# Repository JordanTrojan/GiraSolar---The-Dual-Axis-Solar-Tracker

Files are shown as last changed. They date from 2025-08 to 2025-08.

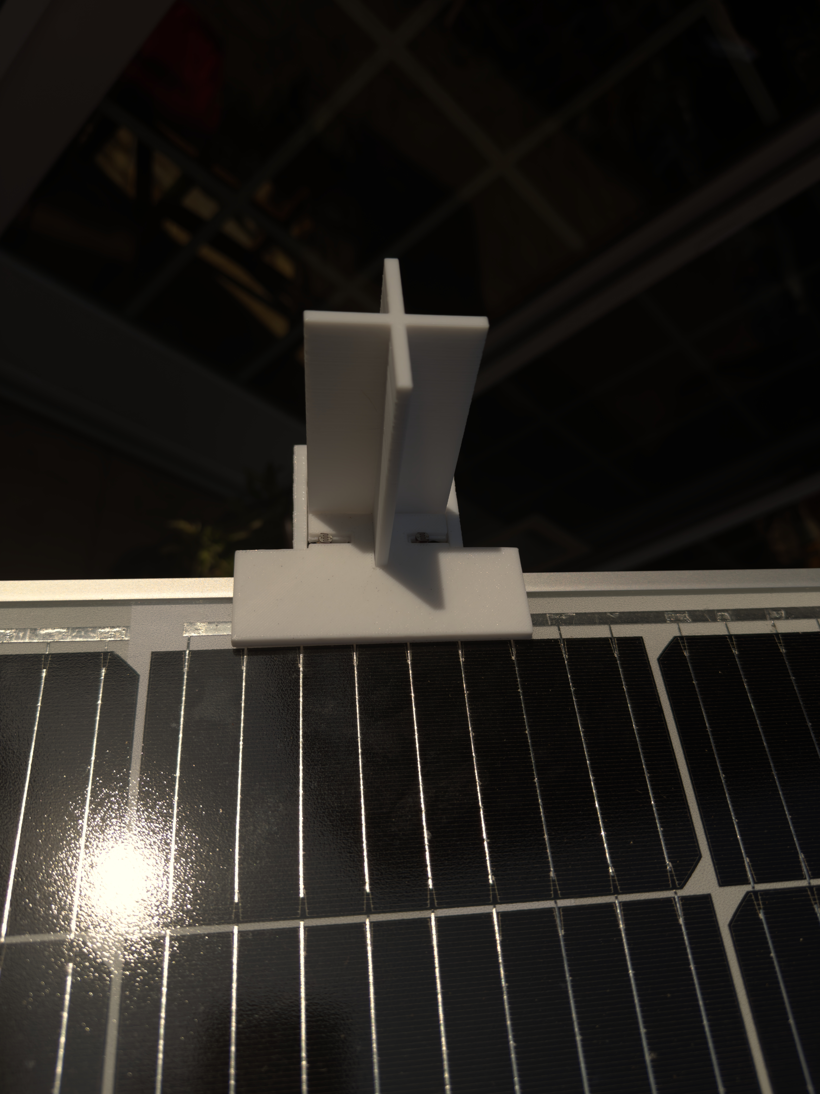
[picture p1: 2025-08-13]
Images and Timelapse/IMG_7817.jpg

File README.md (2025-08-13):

# GiraSolar---The-Dual-Axis-Solar-Tracker
The affordable dual axis solar system that hold up to three solar panels and inceases efficiency by 43% throughout the day. 
The GiraSolar Dual-Axis Tracking Project is an advanced solar tracking system designed to maximize photovoltaic efficiency by keeping the solar panel at the optimal orientation relative to the sun’s position throughout the day and across the seasons. The system operates with a north–south tilt range of 30° to 105° and an east–west rotation range of 45° to 135°, ensuring maximum sunlight exposure from early morning to late afternoon while also maintaining optimal seasonal alignment.

An Arduino Uno microcontroller serves as the control hub, running a custom tracking algorithm. Sun position is determined using an array of photoresistor (LDR) light sensors arranged in a cross-pattern to detect directional light differences. Movement is provided by two high-torque linear actuators—one for NS tilt and one for EW rotation—each driven by a BTS7960 motor driver module for smooth and precise positioning.

The system is powered via a solar charge controller connected to the main panel and battery, ensuring reliable operation in off-grid conditions. To protect the mechanics, limit switches and programmed motion boundaries prevent overextension of the actuators. The frame is made from rigid, lightweight materials, designed for stability under outdoor conditions but not intended for rain or water exposure; as such, the electronics and actuators require a sheltered or dry environment for operation and longevity.

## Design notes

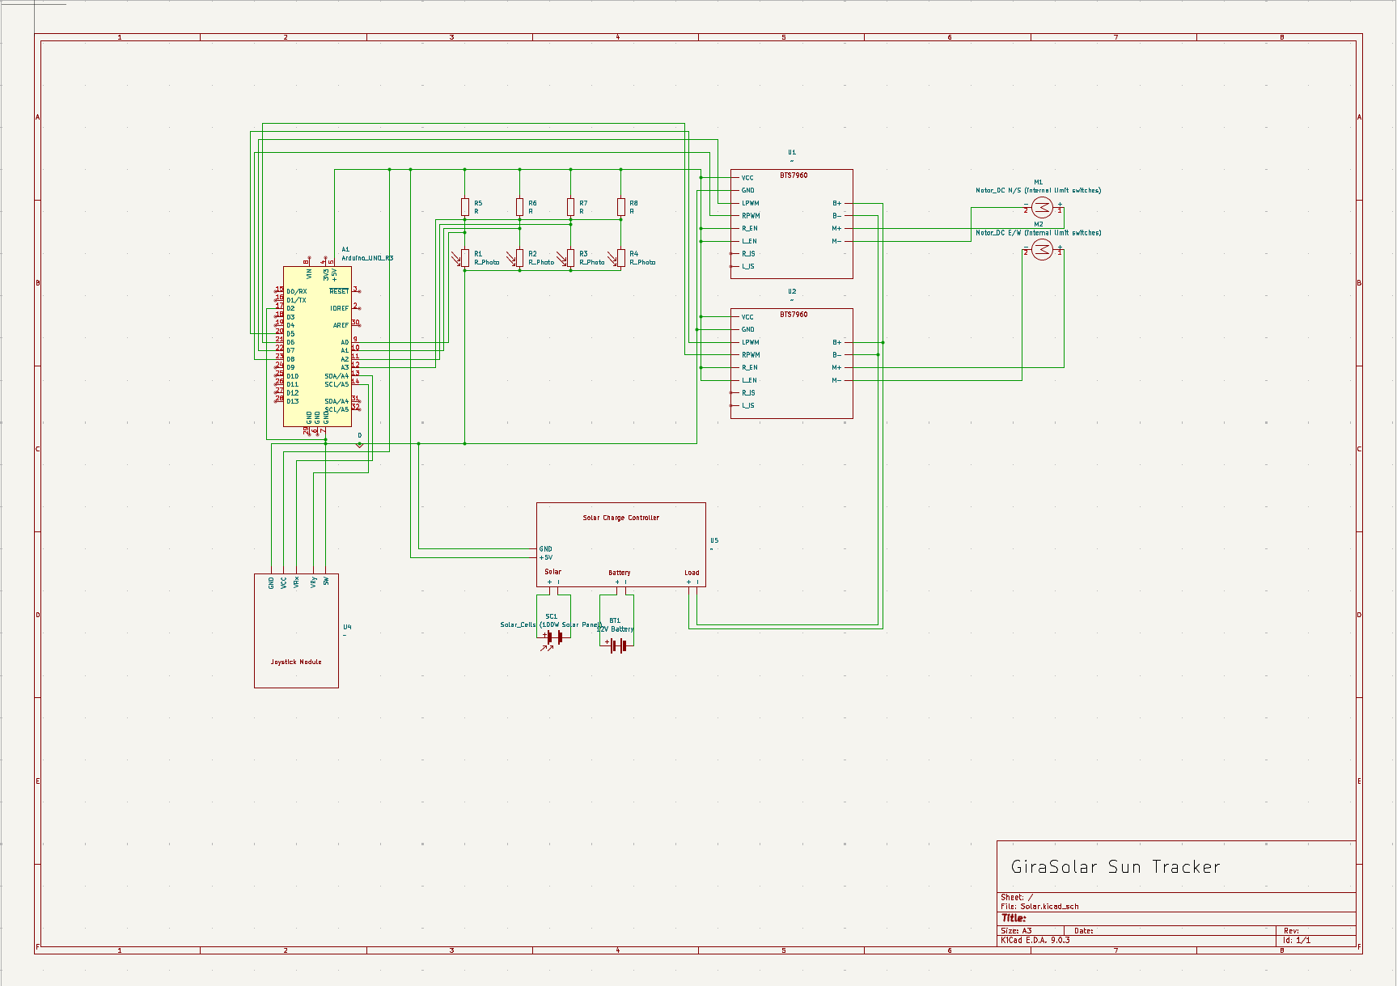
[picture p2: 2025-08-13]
PrototypingAndBudgeting/KiCadSchematic.png

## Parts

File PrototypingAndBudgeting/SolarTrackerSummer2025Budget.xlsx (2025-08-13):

Item | Price | Link
VEVOR Linear Actuator 12V, 12 Inch High Speed 0.55"/s Linear Actuator, 220lbs/1000N Linear Motion Actuator with Mounting Bracket and IP54 Protection | $32.61 | https://www.amazon.com/dp/B0CWNBRKWB?ref=ppx_yo2ov_dt_b_fed_asin_title
Teyleten Robot BTS7960 43A High Power H-Bridge DC Motor Driver Module DC Motor Controller Module for Arduino Smart Car 2pcs | $16.18 | https://www.amazon.com/dp/B099N8XS5P?ref=ppx_yo2ov_dt_b_fed_asin_title
DC Power Supply Variable, Bench Power Supply with Encoder Adjustment Knob, Output Enable/Disable Button, Adjustable Power Supplies with USB Quick-Charge, Short Circuit Alam (30V 5A Black) | $41.75 | https://www.amazon.com/dp/B09BFDZ85C?ref=ppx_yo2ov_dt_b_fed_asin_title
AstroAI Digital Multimeter Tester 2000 Counts with DC AC Voltmeter and Ohm Volt Amp Meter; Measures Voltage, Current, Resistance, Continuity and Diode, Black | $15.21 | https://www.amazon.com/dp/B0CLV8R7QF?ref=ppx_yo2ov_dt_b_fed_asin_title
2Pcs UNO R3 Improved Board, ATmega328P Chip, Compatible with Arduino IDE (with 2 USB Cables) | $13.04 | https://www.amazon.com/dp/B0F1FRNCL8?ref=ppx_yo2ov_dt_b_fed_asin_title
EBOOT 30 Pieces Photoresistor Photo Light Sensitive Resistor Light Dependent Resistor 5 mm (5539) | $6.41 | https://www.amazon.com/dp/B01N7V536K?ref=ppx_yo2ov_dt_b_fed_asin_title
VEVOR Linear Actuator 12V, 12 Inch High Speed 0.55"/s Linear Actuator, 220lbs/1000N Linear Motion Actuator with Mounting Bracket and IP54 Protection | $38.05 | https://www.amazon.com/dp/B0CWNBRKWB?ref=ppx_yo2ov_dt_b_fed_asin_title
HQST Starter 100W 30PWM Controller 1 Piece monocrystalline Silicon Glass Set | $97.86 | https://www.amazon.com/dp/B09PYPBR8P?ref=ppx_yo2ov_dt_b_fed_asin_title
Hilitand USB Cable with Switch, 5pcs USB Male to Female Extension Cord USB Extension Cable with On Off Switch Black | $13.96 | https://www.amazon.com/dp/B0C9MPGD7F?ref=ppx_yo2ov_dt_b_fed_asin_title
Electrical Tape Black,0.7in X 26.5ft,7mil Thick,6 Pack,Industrial Grade Electrical Tape,Multipurpose Electric Tape for Wrapping Wiring Harness,Electric Insulating | $3.25 | https://www.amazon.com/dp/B0CNVXHTM2?ref=ppx_yo2ov_dt_b_fed_asin_title
haisstronica 3:1 Heat Shrink Tubing Kit, Adhesive Lined Marine Resistant Grade Shrink Wrap - 1.75"length 6 Size Perfect for Home and Industrial, 1/8"-3/4" 220PCS - Black, Red | $9.89 | https://www.amazon.com/dp/B0C81FHPHN?ref=ppx_yo2ov_dt_b_fed_asin_title
BNTECHGO 22 Gauge Silicone Wire Spool red 25ft and Black 25ft Flexible 22 AWG Stranded Tinned Copper Wire | $10.85 | https://www.amazon.com/dp/B07HGT44XY?ref=ppx_yo2ov_dt_b_fed_asin_title
Soldering Iron Kit, 90W 110V LCD digital soldering gun，12-in-1 Soldering Iron Kit Tool，Temperature adjustable from 180-480°C，5 soldering tips，soldering wire，soldering paste，soldering pump | $28.26 | https://www.amazon.com/dp/B0BWNDJXBK?ref=ppx_yo2ov_dt_b_fed_asin_title
AIRIC UL Listed Blue Female Spade Connector 16-14 AWG, 100 Pcs Nylon Electrical Crimps Terminal Connectors for Speaker Auto Stereo Wiring Connect Quick Disconnect Crimp Terminals for 16,14 Gauge Wire | $6.08 | https://www.amazon.com/dp/B06XCWHY1B?ref=ppx_yo2ov_dt_b_fed_asin_title
12V 10Ah LiFePO4 Battery, Up to 3000 Deep Cycles Rechargeable Lithium Battery with Built-in 10A BMS for Solar System, Power Wheels, Fish Finder, Outdoor Camping, Scooter | $26.85 | https://www.amazon.com/dp/B0DG2S1NPS?ref=ppx_yo2ov_dt_b_fed_asin_title
Kaisi S-130 Insulation Silicone Soldering Mat Repair Mat, Heat Resistant Silicone Work Mats 932°F with Scale Ruler and Screw Position for Soldering, CellPhone Electronics Repair, Size: 13.8 x 9.8 inch | $0.38 | https://www.amazon.com/dp/B073RFB6BX?ref=ppx_yo2ov_dt_b_fed_asin_title
BNTECHGO 22 Gauge PVC 1007 Solid Electric Wire Red and Black Each 100 ft 22 AWG 1007 Hook Up Tinned Copper Wire | $15.75 | https://www.amazon.com/dp/B07JNB712X?ref=ppx_yo2ov_dt_b_fed_asin_title
TUOFENG 22 awg Wire Solid Core Hookup Wires-6 Different Colored Breadboard Wires 30ft or 9m Each, 22 Gauge Electronic Wire PVC (OD: 1.60mm) Arduino Wires | $16.63 | https://www.amazon.com/dp/B07TX6BX47?ref=ppx_yo2ov_dt_b_fed_asin_title
ElectroCookie Prototype PCB Solderable Breadboard for Electronics Projects Compatible for DIY Arduino Soldering Projects, Gold-Plated (5 Pack + 1 Mini Board, Matte Black) | $9.23 | https://www.amazon.com/dp/B07ZYNWJ1S?ref=ppx_yo2ov_dt_b_fed_asin_title
Soldering Station Helping Hands with Magnifying Glass Third Hand Stand Solder Tool PCB Holder Circuit Board Soldering Kit - Heavy Duty Base Plate | Four Flexible Arms | $21.74 | https://www.amazon.com/dp/B0D59KWLJH?ref=ppx_yo2ov_dt_b_fed_asin_title
Twocorn 63/37 Solder Wire, high Purity no-wash tin-Lead Rosin cored Wire with 1.8% Flux for Electric Soldering (0.8mm 50g) | $4.99 | https://www.amazon.com/dp/B0CP7QHFL6?ref=ppx_yo2ov_dt_b_fed_asin_title
ELEGOO 120pcs Multicolored Dupont Wire 40pin Male to Female, 40pin Male to Male, 40pin Female to Female Breadboard Jumper Ribbon Cables Kit Compatible with Arduino Projects | $7.59 | https://www.amazon.com/dp/B01EV70C78?ref=ppx_yo2ov_dt_b_fed_asin_title
Dad bill (wood materials) | $85.00
6Pcs INA226 I2C IIC Bi-Directional Current Power Monitoring Sensor Module 36V Voltage Detector with Bidirectional Current/Power Monitor Alarm Compatible with Arduino and Embedded Systems | $17.39 | https://www.amazon.com/dp/B0DZ2R5MG5?ref=ppx_yo2ov_dt_b_fed_asin_title
WWZMDiB 3Pcs Micro SD TF Card Adater Reader Module. Support Micro SD Card, Micro SDHC Card for Arduino UNO R3 MEGA 2560 Due | $5.86 | https://www.amazon.com/dp/B0B779R5TZ?ref=ppx_yo2ov_dt_b_fed_asin_title
SanDisk Industrial MLC MicroSD SDHC UHS-I Class 10 SDSDQAF3-008G-I with SanDisk Adapter (8GB) | $4.78 | https://www.amazon.com/dp/B07BZ5SY18?ref=ppx_yo2ov_dt_b_fed_asin_title
HiLetgo 2pcs DS3231 DS3231SN RTC Module Real Time Clock Memory Module V2.0 I2C with PinHeader | $9.23 | https://www.amazon.com/dp/B0832PM954?ref=ppx_yo2ov_dt_b_fed_asin_title
Misc addons for polishing project | $30.00
Total | $588.82
If we wanted to just buy the finished product and not do any engineering + solar panel cost + battery cost | $674.71

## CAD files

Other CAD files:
PrototypingAndBudgeting/GiraSolarFusionFile v1.f3d

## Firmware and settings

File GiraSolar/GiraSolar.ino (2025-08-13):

#include <BTS7960.h>
#include <math.h>
#include <Wire.h>
#include <LiquidCrystal_I2C.h>
#include <Bonezegei_DHT11.h>


#define L_PWM1 12                           
#define R_PWM1 13  
#define L_PWM2 10                           
#define R_PWM2 11  

Bonezegei_DHT11 dht(2);
LiquidCrystal_I2C lcd(0x27, 16, 2);
BTS7960 motor1(-1, -1,R_PWM1, L_PWM1);  
BTS7960 motor2(-1, -1,R_PWM2, L_PWM2);  

void act1(int mode, int time) {
  if (mode > 0) {
      motor1.front();   
  } else if (mode < 0) {
      motor1.back();
  }

  delay(time*1000);
  motor1.stop();
}

void act2(int mode, int time) {
  if (mode > 0) {
      motor2.front();   
  } else if (mode < 0) {
      motor2.back();
  }

  delay(time*1000);
  motor2.stop();
}


void setup() {
  Serial.begin(9600);                      
  motor1.begin();                          
  motor2.begin();
  motor1.stop();                          
  motor2.stop();

  dht.begin();

  Serial.println("\nstarting");
  lcd.init();
  lcd.backlight();
  lcd.setCursor(0, 0);
  lcd.print("Solar Panel");
  delay(2000);
  lcd.setCursor(0, 1);
  lcd.print("Starting up...");

  int i = 255;
  motor1.pwm = i; 
  motor2.pwm = i;
  
 
  act1(-1,10);
  act2(-1,10);



}

void loop() {
  int sensorValueTL = analogRead(A0); 
  int sensorValueTR = analogRead(A1);
  int sensorValueBL = analogRead(A2);
  int sensorValueBR = analogRead(A3);   


  float VoltageTL = (sensorValueTL * 5.0)/1023.0;
  float VoltageTR = (sensorValueTR * 5.0)/1023.0;
  float VoltageBL= (sensorValueBL * 5.0)/1023.0;
  float VoltageBR = (sensorValueBR * 5.0)/1023.0;


  int TopRow = sensorValueTL + sensorValueTR;
  int BottomRow = sensorValueBL + sensorValueBR;

  int LeftCol = sensorValueTL + sensorValueBL;
  int RightCol = sensorValueTR + sensorValueBR;
 

  dht.getData();                        
  int tempFar = dht.getTemperature(true); 
  int hum = dht.getHumidity();               


  lcd.init();
  lcd.backlight();
  lcd.clear();
  
  lcd.setCursor(0, 0);
  lcd.print(VoltageTL,2);
  lcd.print("V ");
  lcd.print(VoltageTR,2);
  lcd.print("V ");
  lcd.print(tempFar);
  lcd.print("F");

  lcd.setCursor(0, 1);
  lcd.print(VoltageBL,2);
  lcd.print("V ");
  lcd.print(VoltageBR,2);
  lcd.print("V ");
  lcd.print(hum);
  lcd.print("%");

  Serial.print(sensorValueTL);
  Serial.print("    ");
  Serial.println(sensorValueTR);
  Serial.print(sensorValueBL);
  Serial.print("    ");
  Serial.println(sensorValueBR);
  Serial.println();

  if ((fabs(TopRow-BottomRow)>50)) {
    if (TopRow>BottomRow) {
      act1(-1,1);
    } else {
      act1(1,1);
    }
  }
  

  if ((fabs(LeftCol-RightCol)>50)) {
    if (LeftCol>RightCol) {
      act2(-1,1);
    } else {
      act2(1,1);
    }
  }

  delay(5000);


 
}

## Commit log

2025-08-13 Project upload 1
    [GiraSolar v1.f3d, Solar Tracker Summer 2025.xlsx, Solar.kicad_sch]
2025-08-13 Rename Solar Tracker Summer 2025.xlsx to SolarTrackerSummer2025Budget.xlsx
    [SolarTrackerSummer2025Budget.xlsx]
2025-08-13 Rename GiraSolar v1.f3d to GiraSolarFusionFile v1.f3d
    [GiraSolarFusionFile v1.f3d]
2025-08-13 Rename KiCadSchematic.png to KiCadSchematic.png /PrototypingAndBudgeting
2025-08-13 Rename KiCadSchematic.png to PrototypingAndBudgeting /KiCadSchematic.png
2025-08-13 Rename GiraSolarFusionFile v1.f3d to PrototypingAndBudgeting / GiraSolarFusionFile v1.f3d
    [GiraSolarFusionFile v1.f3d]
2025-08-13 Update and rename Solar.kicad_sch to PrototypingAndBudgeting/Solar.kicad_sch
    [Solar.kicad_sch]
2025-08-13 Rename GiraSolarFusionFile v1.f3d to GiraSolarFusionFile v1.f3d
    [GiraSolarFusionFile v1.f3d]
